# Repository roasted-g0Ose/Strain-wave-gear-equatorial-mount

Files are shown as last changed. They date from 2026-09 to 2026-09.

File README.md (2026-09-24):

# Strain Wave Gear Equatorial Mount
## What is an equatorial mount?

An **equatorial mount** is a telescope mount designed to compensate for the Earth's rotation and track celestial objects as they move across the sky. It consists of two axes known as the **right ascension (RA)** and **declination (DEC)**.

The RA axis is aligned parallel to the Earth's rotational axis, allowing the mount to rotate at the same rate as the sky appears to move. By continuously rotating around the RA axis, the mount can effectively cancel out the Earth's rotation and keep a celestial object centered in the telescope's field of view.

The DEC axis is perpendicular to the RA axis and is used to adjust the telescope's position north or south of the celestial equator. By controlling both the RA and DEC axes, the mount can slew to a specific celestial coordinate and point the telescope at a desired object in the night sky. Once positioned, the RA axis can continue tracking the object as the Earth rotates.

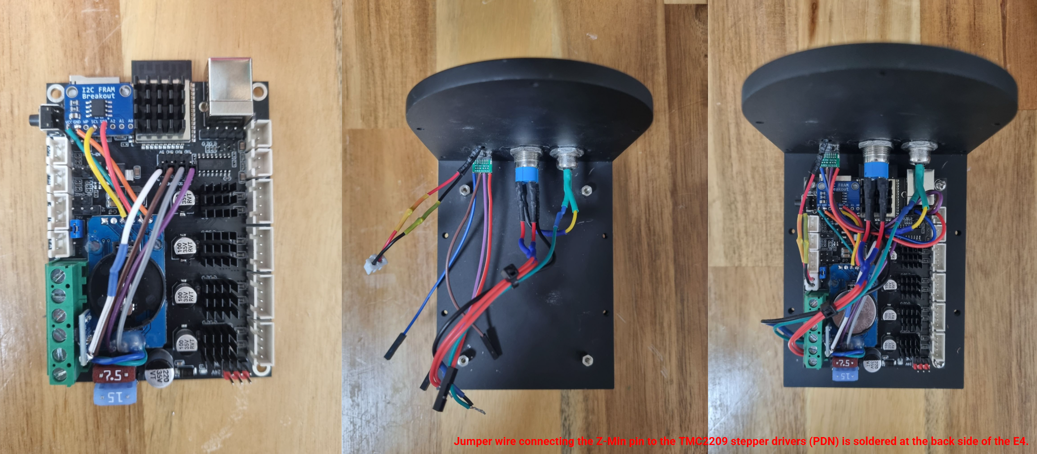
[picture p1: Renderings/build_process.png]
build_process

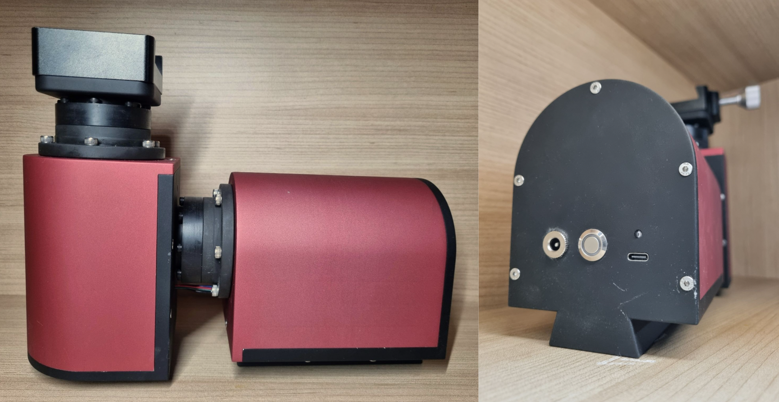
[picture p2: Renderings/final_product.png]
final_product


## Comparison of Primary Reduction Gears

When building a strain wave gear equatorial mount yourself, one of the key decisions is which primary reduction gear to use. Each type of reduction gear has its own pros and cons, summarized in the table below.

| | Planetary gear | Belt drive | Direct drive (no reduction) | Strain wave gear |
|---|---|---|---|---|
| **Backlash** | Present | None | None | None |
| **Periodic error** | Small | Almost none | None | Somewhat present |
| **Maintenance** | Barely needed | Needed (tension adjustment) | Barely needed | Barely needed |

Although the third and fourth options are attractive for their low maintenance (requiring no tension adjustment over time) and zero-backlash design, I was unaware of their existence at the time.

## Features
* FRAM module saves current position every 1000ms from start-up (home position) enabling return if there is an accidental power outage (e.g., tripping over the power cable).
* RTC module keeps track of the current time and date even when the mount is turned off.
* High reduction ratio at 2000:1 eliminates the need for electromagnetic brakes.
* Supports pulse guiding via via USB-C (USB 2.0).
* Theoretical payload of 7kg without counterweight, 12kg with counterweight.

## Bill of materials
### BOM - Electronics
| Component | Price/unit (USD)* | Quantity |
|---|---|---|
| AMS1117-3.3 3PIN | $0.34 | 1 |
| USB Type-C Female Socket | $0.37 | 1 |
| DC-099 5.5x2.1mm Female Socket | $0.47 | 1 |
| 3φ 5V LED** | $0.48 | 1 |
| 40PCS 10cm female-to-female Dupont jumper wire | $0.89 | 1 |
| 40PCS 10cm female-to-male Dupont jumper wire | $0.94 | 1 |
| 40PCS 10cm male-to-male Dupont jumper wire | $1.04 | 1 |
| MB85RC256V I2C FRAM Memory Module | $2.96 | 1 |
| DS3231 RTC Module | $2.34 | 1 |
| 12mm push button with latching reset 9-30V(12V)** | $3.15 | 1 |
| 17HS4401 NEMA17 Stepper Motor | $4.66 | 2 |
| FLE42-L2SW (20:1) | $18.46 | 2 |
| FYSETC E4 | $26.34 | 1 |
| ZXS14 (100:1, for shaft diameter of 8mm) | $85.40 | 2 |

### BOM - Mechanical
| Component | Price/unit (USD) | Quantity |
|---|---|---|
| Phillips Round Head Screw, M3 x 3 | $0.02 | 4 |
| Hex Socket Countersunk Head Screw, M3 x 12 | $0.03 | 10 |
| Hex Socket Countersunk Head Screw, M3 x 15 | $0.03 | 8 |
| PCB Standoff, M3 x 5 | $0.05 | 4 |
| Hex Socket Countersunk Head Screw, M4 x 10 | $0.05 | 8 |
| Hex Socket Head Cap Screw, M4 x 12 | $0.05 | 3 |
| Hex Socket Countersunk Head Screw, M4 x 12 | $0.05 | 4 |
| Hex Socket Head Cap Screw, M4 x 20 | $0.06 | 12 |
| Hex Socket Head Cap Screw, M6 x 10 | $0.10 | 4 |
| Hex Socket Head Cap Screw, M4 x 18 | $0.10 | 6 |
| Dovetail holder | $12.95 | 1 |
| Super Lube MULTI-PURPOSE SYNTHETIC GREASE WITH SYNCOLON (PTFE) | $18.03 | 1 |
| Loctite 638 | $18.50 | 1 |
| CNC machined parts (6 in total, tariff excluded) | $639.31 | 1 |
| Heat shrink set | $2.66 | 1 |

| | Total |
|---|---|
| **Total BOM Cost (USD)** | $951.10 |

*Calculated based on the current (Sep 7th 2026) exchange rate of 1 KRW = $0.00074.  
**Emits red light.

## Code
I made several changes to the default [OnStepX-E4](https://github.com/hjd1964/OnStepX/tree/E4) code. 

```cpp
// Extra code added under #define STATUS_LED                     ON
#define STATUS_LED_ON_STATE          HIGH
```

```cpp
// This build does not utilize weather sensors of any sort.
#define WEATHER               OFF 
```

```cpp
// Positional memory retention via Adafruit MB85RC256V FRAM breakout (I2C).

#define NV_DRIVER      NV_MB85RC256
#define MOUNT_COORDS_MEMORY      ON
```

```cpp
// Relevant steps per degree was calculated here: http://www.stellarjourney.com/assets/downloads/OnStep%20Calculations%20134.xlsx

#define AXIS1_STEPS_PER_DEGREE      35555.55556
#define AXIS2_STEPS_PER_DEGREE      35555.55556
```

```cpp
// These options can be toggled ON and OFF for reversal of direction of rotation. 
// As you can see, my RA axis was somewhat rotating in the wrong direction.

#define AXIS1_REVERSE      ON
#define AXIS2_REVERSE      OFF
```

```cpp
// DS3231 settings were left at default. 
#define TIME_LOCATION_SOURCE       DS3231
```

```cpp
// Not a worm gear mount, fast guiding compensates for PE (Periodic Error)
#define PEC_STEPS_PER_WORM_ROTATION        0
```
```cpp
#define TRACK_AUTOSTART      ON
```

```cpp
// Although adjustable at run-time from 1/2 to 2x this rate, it is not recommended to go over 1.0 deg/sec as it may cause step-out.
#define SLEW_RATE_BASE_DESIRED        1.0

```

For uploading instructions, please refer to [OnStep Wiki](https://onstep.groups.io/g/main/wiki/32794). Although the wiki does not mention it explicitly, you will need to install the latest Adafruit BusIO library since this is a dependency for the Adafruit BME280 library (I have included ZIP files of [required libraries](./SW/Libraries/) inside the repository).

## Troubleshooting
### No response to serial commands (`:GVP#` returns nothing)
**Cause:** `NV_DRIVER` was set to `NV_MB85RC256` (external I2C FRAM) before the FRAM module was wired up. OnStepX hung indefinitely trying to write defaults to a non-existent NV device, so it never reached the point of starting the command channel.

**Fix:** Wire the FRAM to I2C before power-on, or temporarily switch `NV_DRIVER` to `NV_DEFAULT` (internal flash) if testing without it. After connecting/switching NV devices, run one `NV_WIPE ON` → upload → power cycle → wait ~1 min → `NV_WIPE OFF` → upload cycle to initialize the device's defaults.

### Status LED never lights
**Cause:** `STATUS_LED_PIN` on the E4 is routed through a MOSFET-switched fan header (V-Fan), which is active-HIGH. OnStepX's default LED logic assumes a raw cathode-sink pin (active-LOW), so it was driving the pin the opposite way needed to turn the LED on.

**Fix:** Add `#define STATUS_LED_ON_STATE HIGH` below `STATUS_LED ON` in Config.h.

### NINA shows ASCOM checksum / invalid drive rate errors
**Cause:** `DEBUG` was left set to `VERBOSE` in Extended_config.h. Since `SERIAL_DEBUG` shares the same physical port as the command channel (`SERIAL_A`), debug text was interleaved with LX200 protocol replies, corrupting what NINA received.

**Fix:** Set `DEBUG OFF` for normal operation; only enable `VERBOSE` for boot-log diagnostics with NINA disconnected.

### Status LED (and mount state) resets when opening the NINA OnStep Telescope Setup tab
**Cause:** ESP32 dev boards including the E4 have a built-in auto-reset circuit. The DTR and RTS lines from the USB-serial chip are wired through transistors to the ESP32's EN (reset) pin. This was originally intended to let the Arduino IDE reset the board automatically during firmware uploads. However, any application that opens the COM port, including NINA and ASCOM, can inadvertently trigger a reset. If RTS is held low while the port remains open, it can even keep the board in a reset state for the entire time the tab is open.

The behavior was inconsistent. Sometimes the LED would come back on after a full reboot cycle, but often it would never come back at all. This is likely caused by repeated connection retries reasserting DTR during the reboot process before the board has a chance to finish booting.

**Fix (soft and hard fixes):**
* In the ASCOM OnStep driver's Setup dialog, set the Serial Interface baud dropdown to the **"no DTR control"** variant. This does not prevent Status LED reset upon opening the NINA OnStep Telescope Setup tab, but makes sure the LED comes back on after a full reboot cycle.
* In Windows Device Manager → Ports → [COM port] → Properties → Port Settings → Advanced, enable **"Disable Modem Ctrl Handshaking."** This completely prevents Status LED reset.

### NINA's home position function does not work and GOTO function immediately settles
**Cause:** FRAM module is corrupt.

**Fix:** Replace FRAM.

### Mount behaves normally when the housing is not mounted, while it behaves abnormally when the housing is mounted
**Cause:** The reset switch on the board is physically pressed against the mount housing.

**Fix:** Trim off the end of the reset switch.

## Room for further improvement
* 3D print a non-metallic panel to provide easier access to the mount's power and control interfaces.

* Use a strain wave gear as the primary reducer instead of planetary gear to eliminate backlash while maintaining a high reduction ratio.

* Add a buzzer to provide audible feedback on the mount's status, making it possible to monitor its state without having to look at the mount.

* Add another opening for the onboard USB-B connector. It is structurally more rigid and can serve as a backup interface in the field if the USB-C port fails.

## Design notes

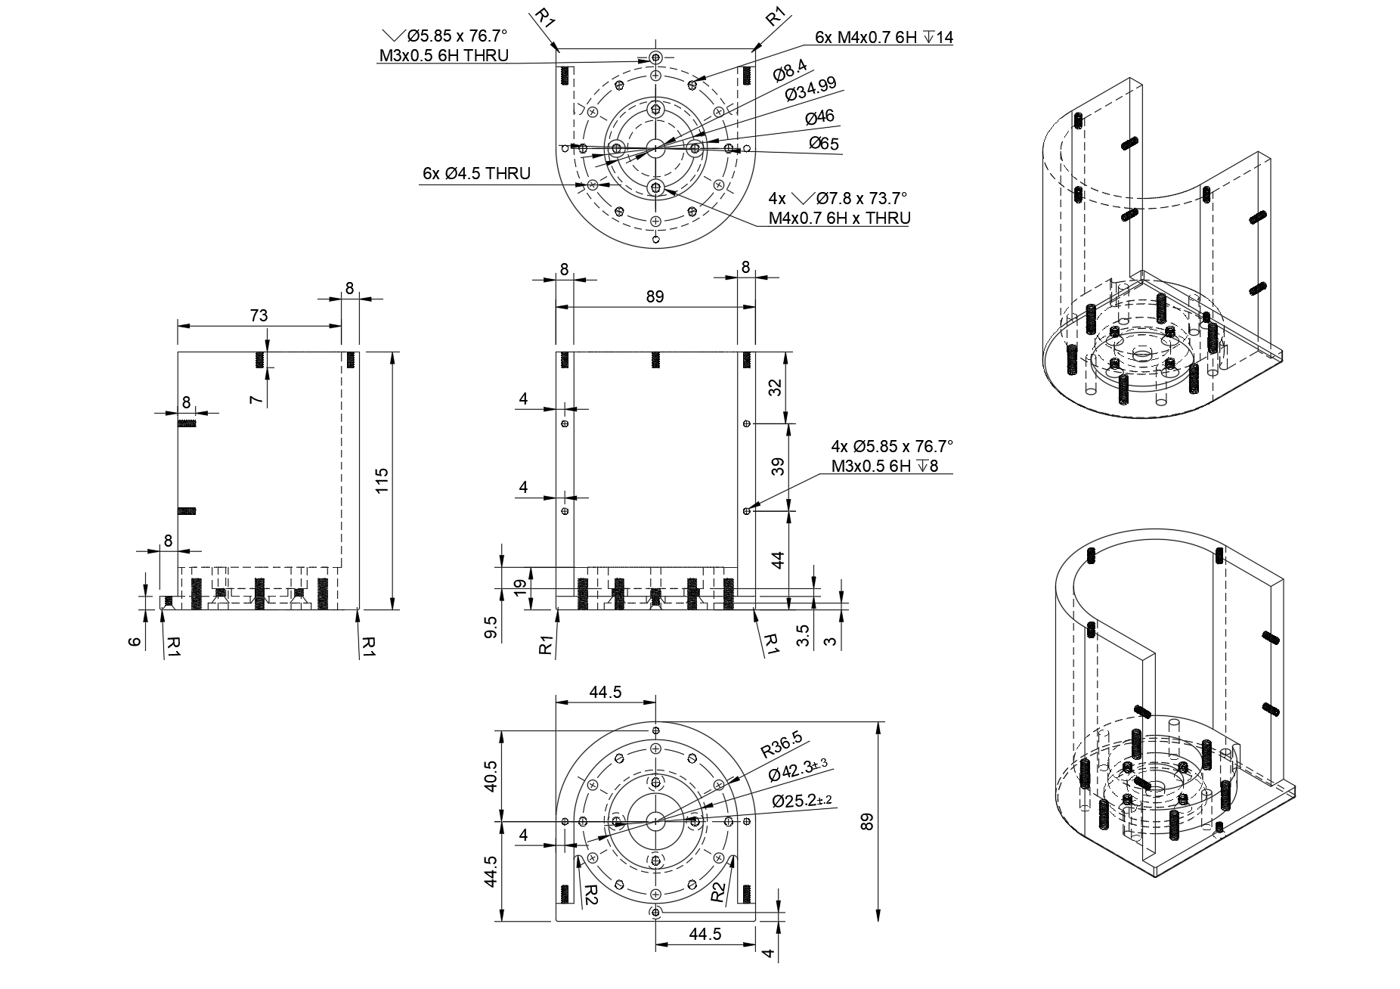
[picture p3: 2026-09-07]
2D Drawings/Declination/DEC1 Drawing.png

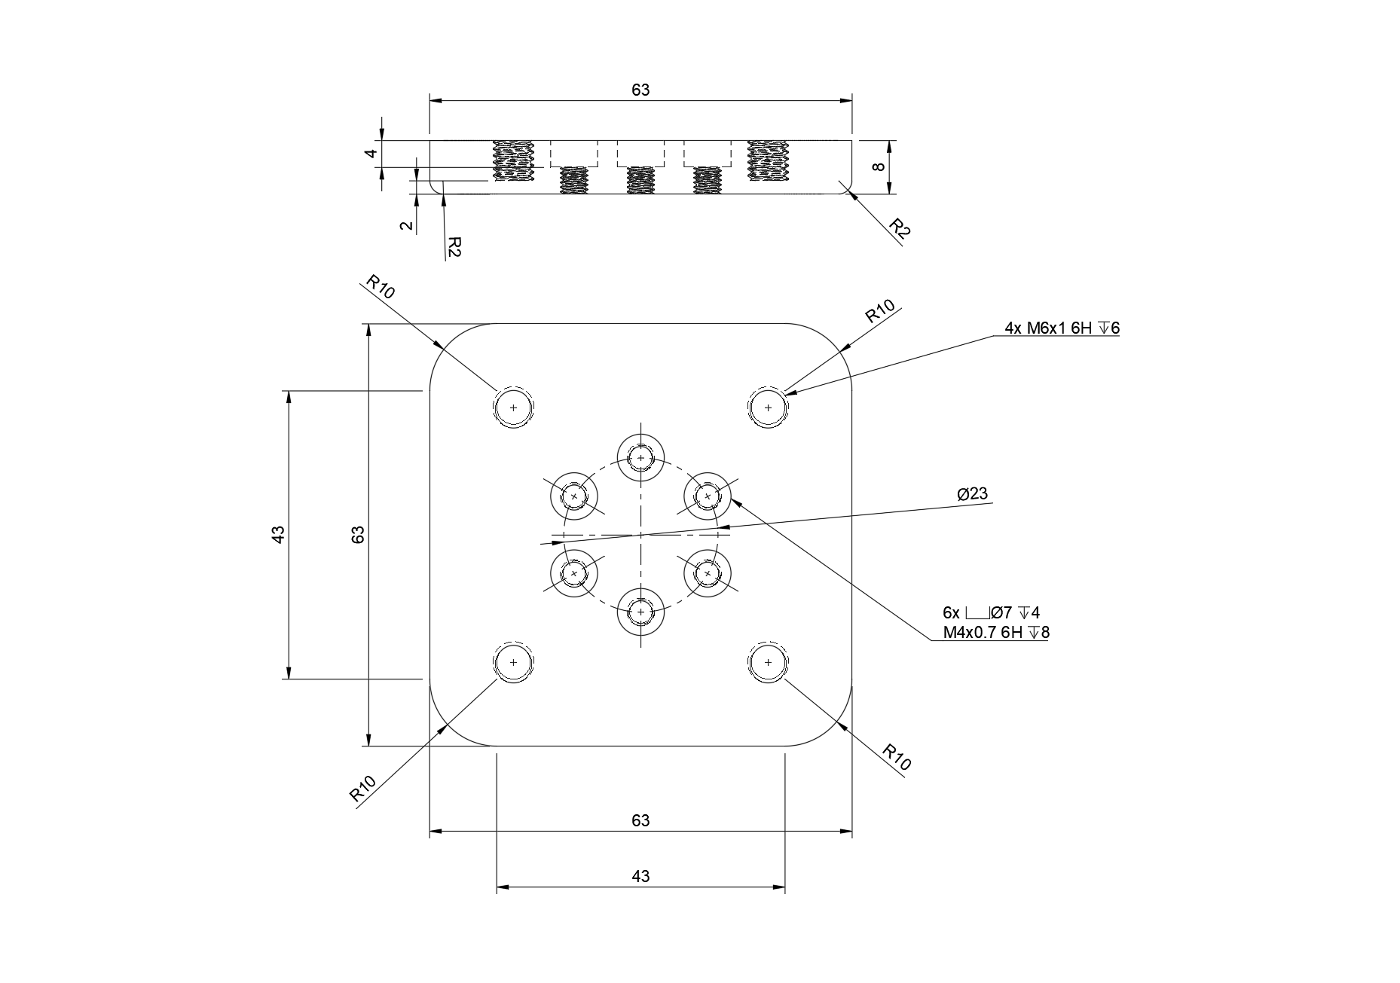
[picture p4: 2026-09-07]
2D Drawings/Declination/Clamp-harmonic Adapter Drawing.png

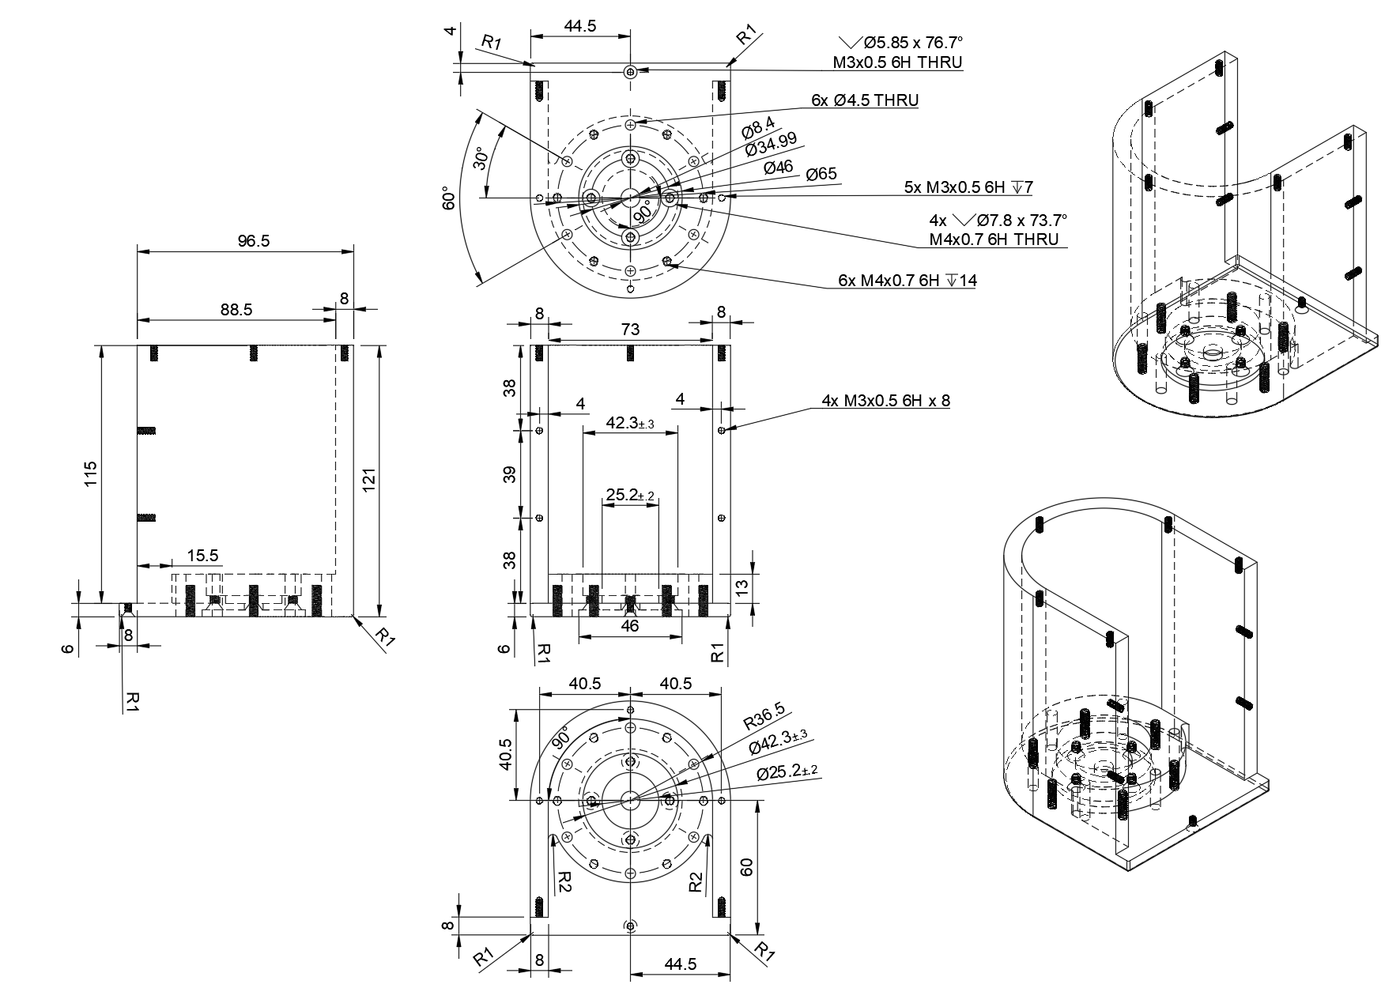
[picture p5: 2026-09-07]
2D Drawings/Right Ascension/RA1 Drawing.png

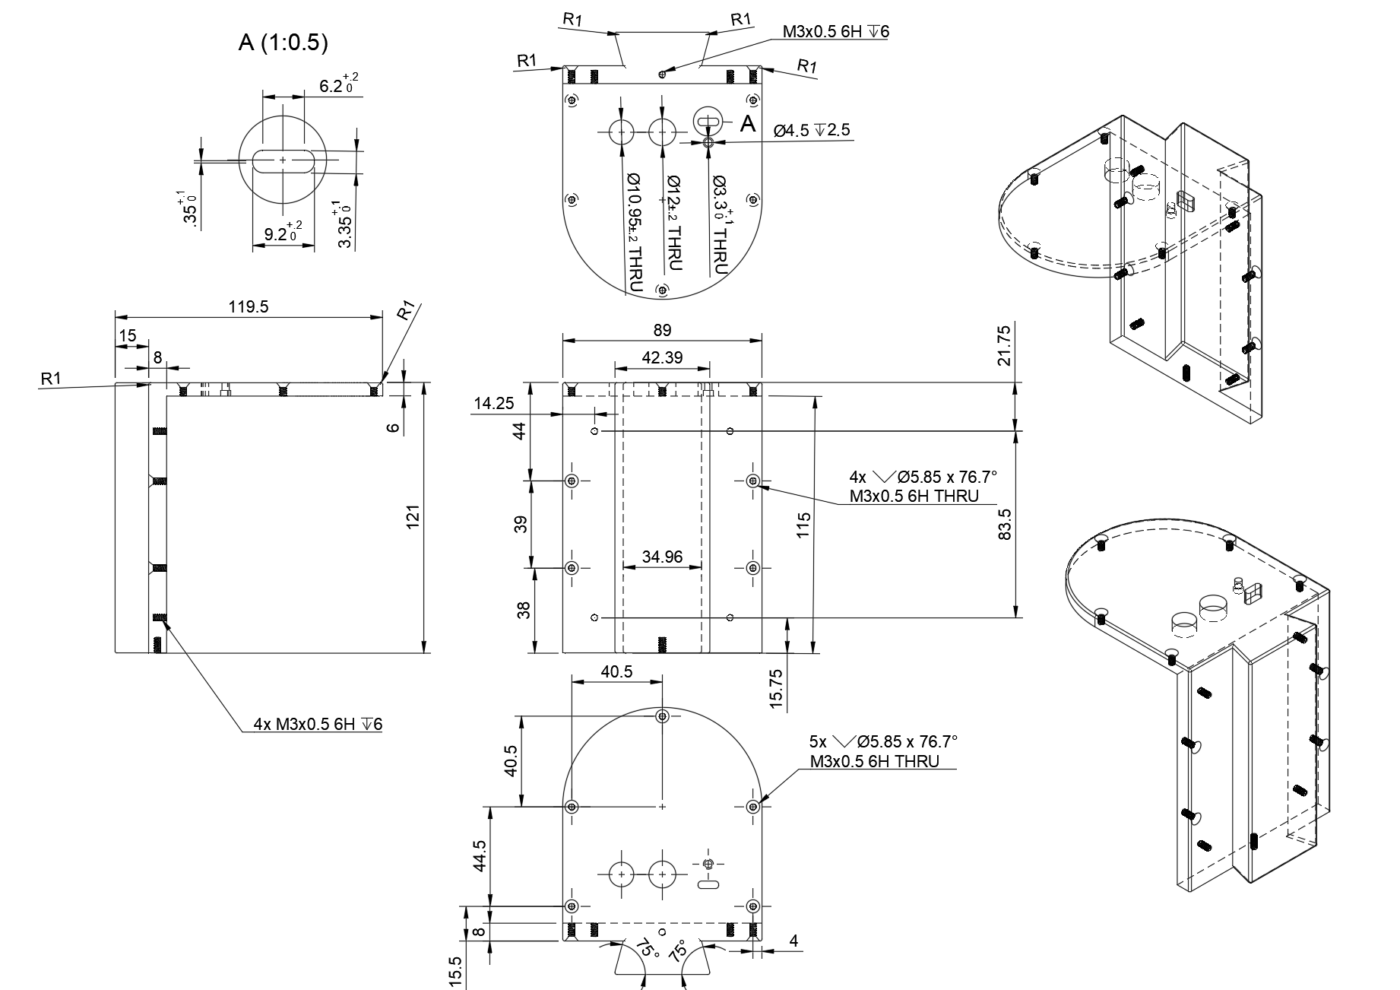
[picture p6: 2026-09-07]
2D Drawings/Right Ascension/RA2 Drawing.png

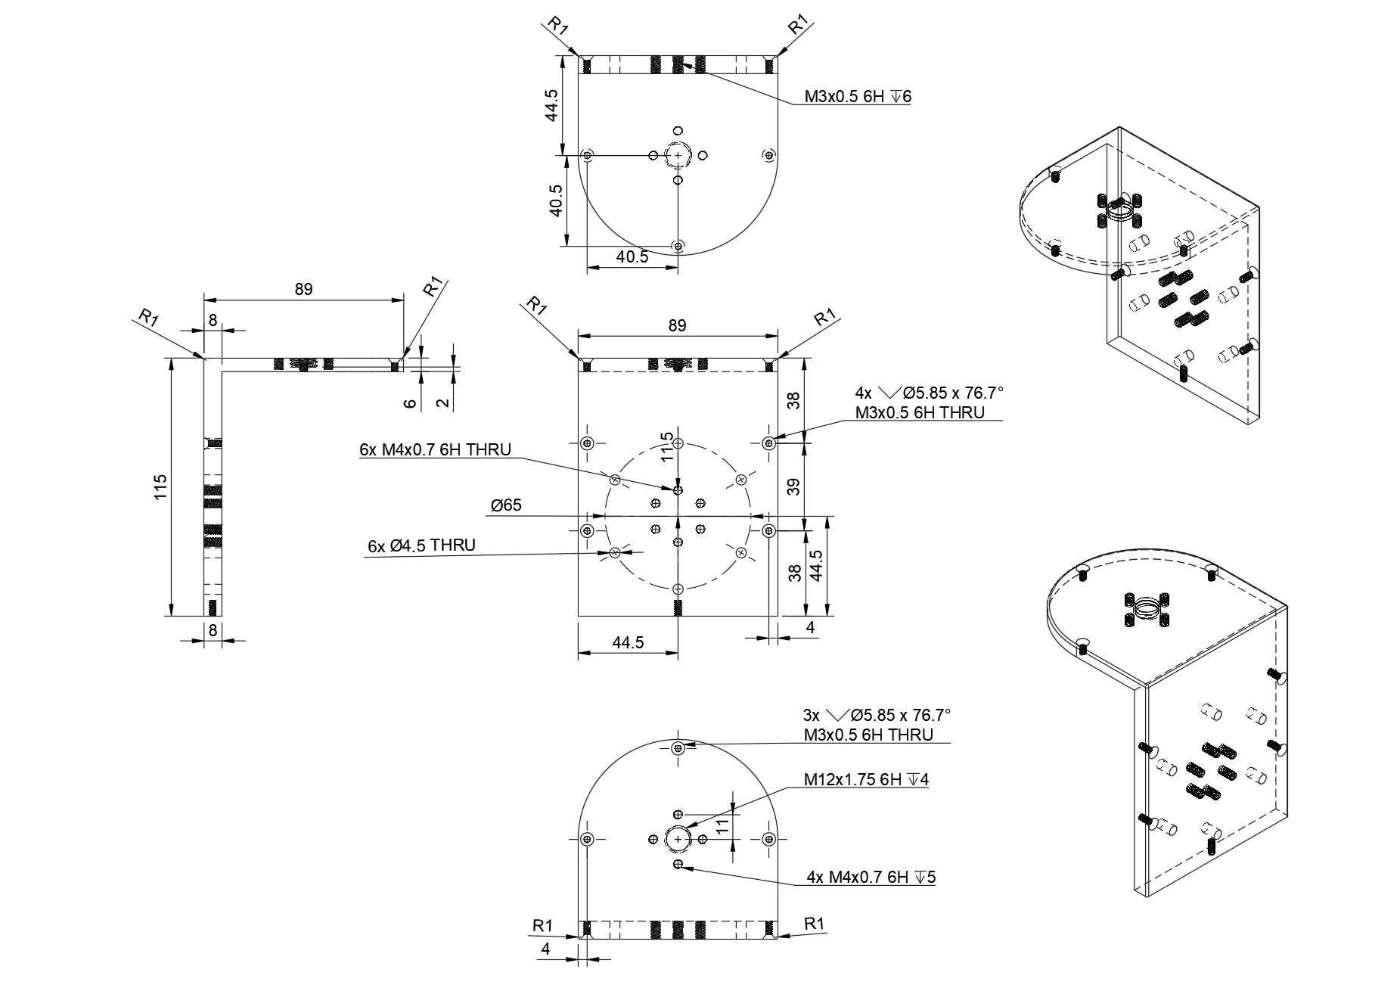
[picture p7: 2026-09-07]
2D Drawings/Declination/DEC2 Drawing.png

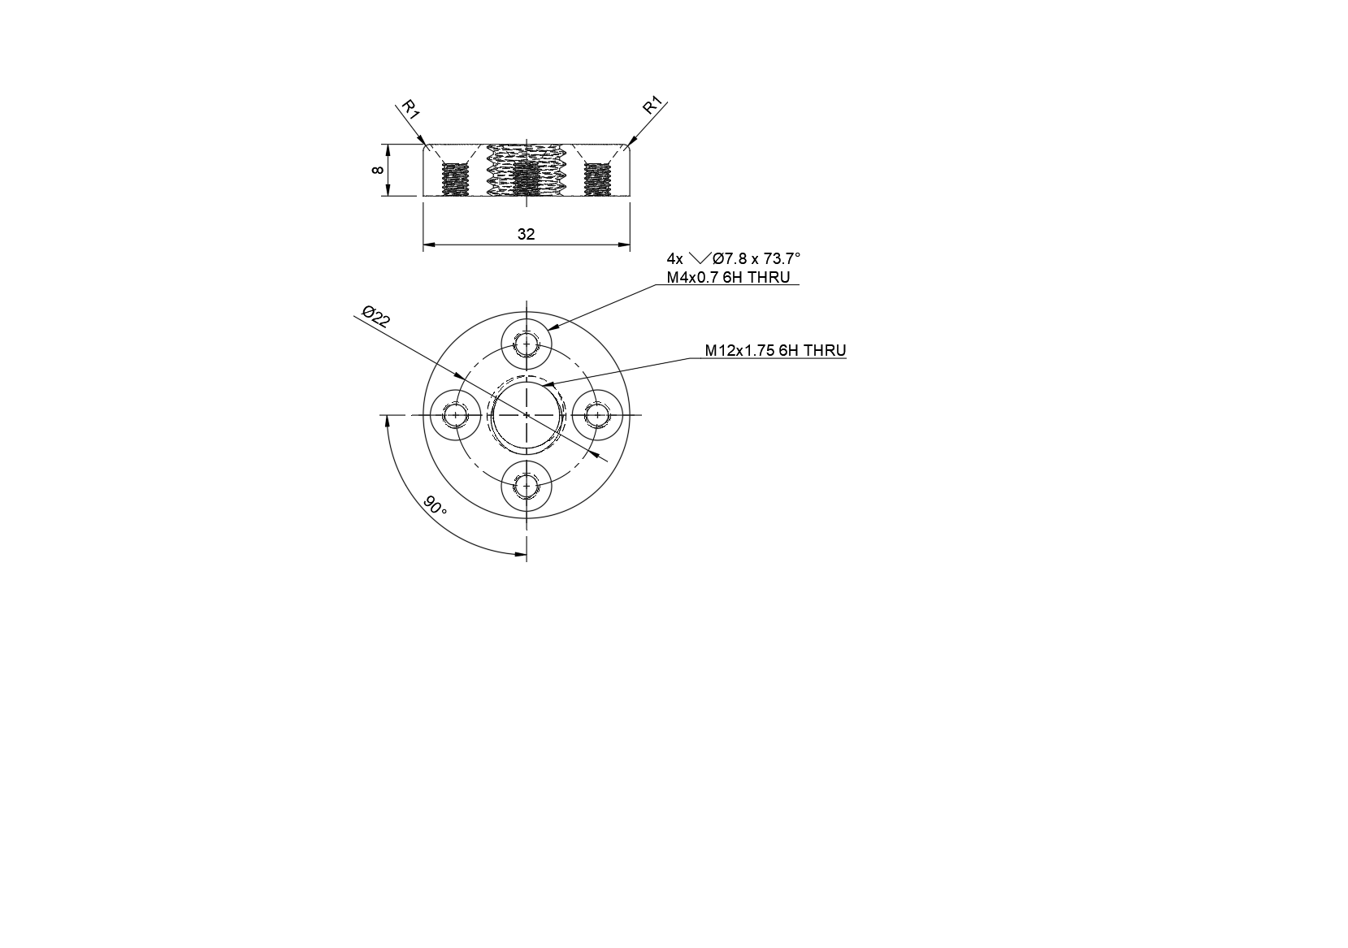
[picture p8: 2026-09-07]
2D Drawings/Declination/Counterweight Shaft Holder Drawing.png

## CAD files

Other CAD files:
3D Models/Assembly.step
3D Models/Declination/DEC1.step
3D Models/Right Ascension/RA1.step
3D Models/Declination/Clamp-harmonic Adapter.step
3D Models/Right Ascension/RA2.step
3D Models/Declination/Counterweight Shaft Holder.step
3D Models/Declination/DEC2.step

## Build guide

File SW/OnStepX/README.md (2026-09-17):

OnStepX Telescope Controller
===========================
# What is OnStepX?
OnStepX is the advanced version of the OnStep computerized telescope controller with support for interfacing with/controlling a variety of motor drivers (and so motors) including Step/Dir, ODrive, and Servo (a combination of encoder and DC motor or Stepper motor) types.

It supports:
* Telescope Mount control (Alt/Azm and Equatorial GEM/Fork.)  Optional support for Eq mounts with Tangent Arm Declination.  Usually the Goto capability is enabled, but that's optional as well for those who just want basic mount control.
* Telescope Rotator control (including Alt/Azm de-rotation.)
* Telescope Focuser control (up to 6 focusers so it can handle collimation as well as focusing.)
* Telescope Accessory control (combination of up to 8 dew-heaters, switches, analog PWM.)

# Features
OnStepX supports a wide variety of connection options.  Several serial
"command channels" can be utilized. One of the these is normally devoted to a USB
connection and for the other(s) choose from the following:

* Bluetooth
* ESP8266 WiFi
* Arduino M0/Ethernet Shield
* Even another USB port or RS232 serial isn't very difficult to add.

In the case of running OnStepX on an ESP32 it can provide its own Bluetooth or WiFi IP command channels without additional hardware by simply activating the feature in OnStepX.

Other software in the OnStep ecosystem include:

* an [ASCOM](http://ascom-standards.org/) driver (with IP and Serial support),
* an Android App useable over WiFi or Bluetooth equipped Phones/Tablets,
* a "built-in" website (on the Ethernet and/or WiFi device),
* a full planetarium program that controls all features ([Sky Planetarium](http://stellarjourney.com/index.php?r=site/software_sky)).

OnStep is compatible with the LX200 protocol. This means it can be controlled
from other planetarium software, like: Sky Safari, CdC (even without ASCOM),
Stellarium, etc.

There are also [INDI](http://www.indilib.org/about.html) drivers so it can be used from Linux, with CdC or KStars.

# Documentation
Detailed documentation, including the full set of features, detailed designs for
PCBs, instructions on how to build a controller, how to configure the firmware
for your particular mount, can all be found the [OnStep Group Wiki](https://groups.io/g/onstep/wiki/home).

# Change Log
All the changes are tracking in git, and a detailed list can be accessed using the
following git command:
 
git log --date=short --pretty=format:"%h %ad %<(20)%an %<(150,trunc)%s"

# Support
Questions and discussion should be on the mailing list (also accessible via the
web) at the [OnStep Group](https://groups.io/g/onstep/).

# License
OnStep is open source free software, licensed under the GPL.

See [LICENSE.txt](./LICENSE.txt) file.

# Author
[Howard Dutton](http://www.stellarjourney.com)

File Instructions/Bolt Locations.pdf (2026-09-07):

Hex Socket Head Cap Screw, M4 x 20 (Qty: 6)

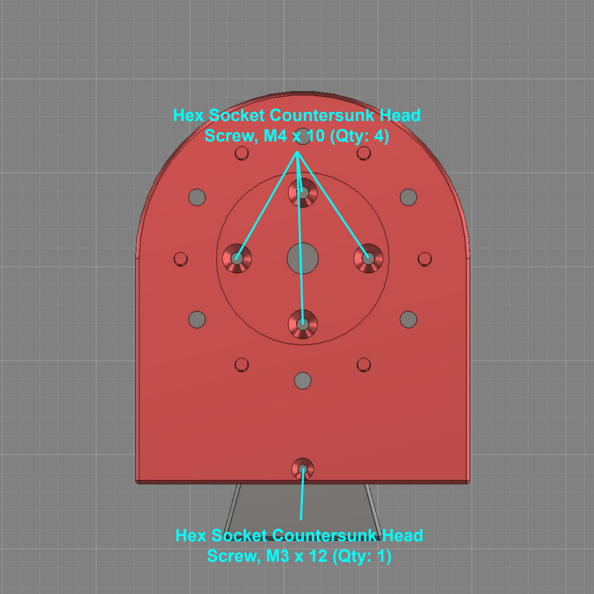
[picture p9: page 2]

Hex Socket Countersunk Head Screw, M4 x 10 (Qty: 4)

Hex Socket Countersunk Head Screw, M3 x 12 (Qty: 1)

Hex Socket Countersunk Head Screw, M3 x 15 (Qty: 4)

Hex Socket Countersunk Head Screw, M3 x 12 (Qty: 4)

PCB Standoff, M3 x 5 (Qty: 4) + Phillips Round Head Screw, M3 x 3 (Qty: 4)

Hex Socket Head Cap Screw, M4 x 12 (Qty: 3)

Hex Socket Head Cap Screw, M6 x 10 (Qty: 4)

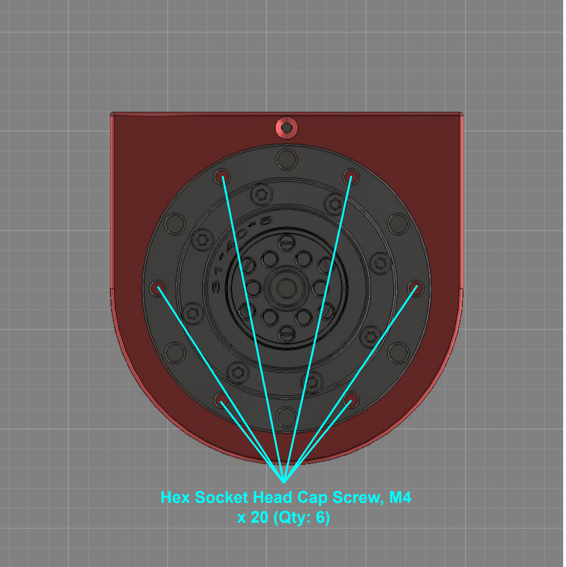
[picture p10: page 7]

Hex Socket Head Cap Screw, M4 x 20 (Qty: 6)

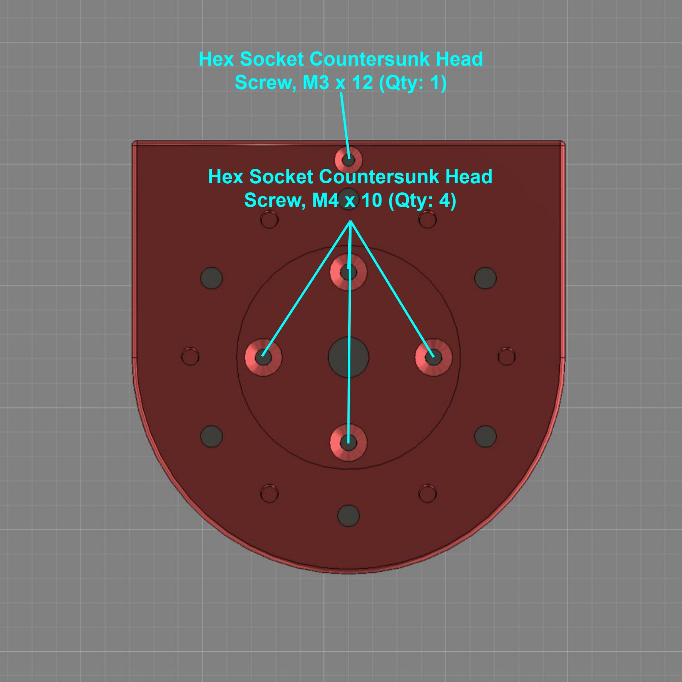
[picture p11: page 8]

Hex Socket Countersunk Head Screw, M4 x 10 (Qty: 4)

Hex Socket Countersunk Head Screw, M3 x 12 (Qty: 1)

Hex Socket Countersunk Head Screw, M4 x 12 (Qty: 4)

Hex Socket Countersunk Head Screw, M3 x 12 (Qty: 4)

Hex Socket Countersunk Head Screw, M3 x 15 (Qty: 4)

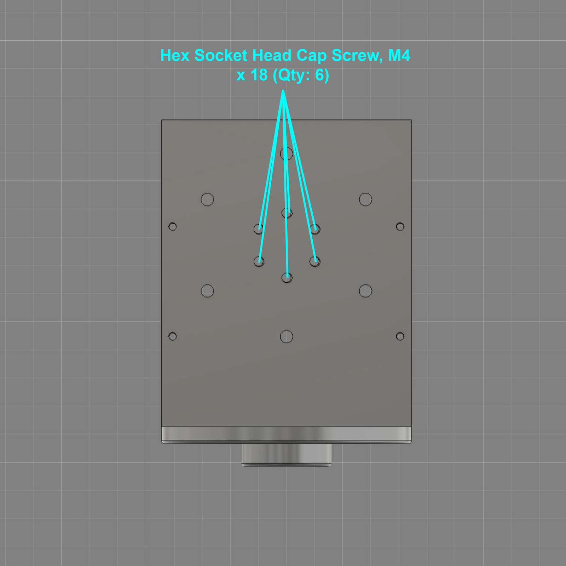
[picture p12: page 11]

Hex Socket Head Cap Screw, M4 x 18 (Qty: 6)

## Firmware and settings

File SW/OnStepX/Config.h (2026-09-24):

/* ---------------------------------------------------------------------------------------------------------------------------------
 * Configuration for OnStepX
 *
 *          For more information on setting OnStep up see http://www.stellarjourney.com/index.php?r=site/equipment_onstep 
 *                      and join the OnStep Groups.io at https://groups.io/g/onstep
 * 
 *           *** Read the compiler warnings and errors, they are there to help guard against invalid configurations ***
 *
 * ---------------------------------------------------------------------------------------------------------------------------------
 * ADJUST THE FOLLOWING TO CONFIGURE YOUR CONTROLLER FEATURES ----------------------------------------------------------------------
 * <-Req'd = always must set, <-Often = usually must set, Option = optional, Adjust = adjust as req'd, Infreq = infrequently changed
*/
//      Parameter Name              Value   Default  Notes                                                                      Hint

// =================================================================================================================================
// CONTROLLER ======================================================================================================================

#define THERMISTOR1_TNOM               25 //         Nominal temperature (Celsius)
#define THERMISTOR1_RNOM            10000 //         Nominal resistance (Ohms) at nominal temperature
#define THERMISTOR1_BETA             3950 //         Beta coefficient
#define THERMISTOR1_RSERIES          4700 //         Series resistor value (Ohms)
//#define THERMISTOR_RPARALLEL      10000 //         Parallel resistor value (Ohms, requires adding the 10k resistors to TB/TE!)
                                          //         Option to extend the temperature measurement range down to -20C or so

#define LIMIT_SENSE_PIN                34 //         Override default and move limit sense to the FYSETC E4's X-MIN connector
#define SERIAL_TMC_RX                  35 //         Override default TMC2209 RX pin move to Y-MIN (enable _DRIVER_STATUS to use)

#define DISPLAY_WEATHER                ON //         Website, display weather
#define DISPLAY_INTERNAL_TEMPERATURE   ON //         Website, display internal MCU temperature

// PINMAP ------------------------------------------------- see https://onstep.groups.io/g/main/wiki/Configuration_Controller#PINMAP
#define PINMAP                  FYSETC_E4 //    OFF, Choose from: MiniPCB, MiniPCB2, MaxPCB2, MaxESP3, CNC3, STM32Blue,      <-Req'd
                                          //         MaxSTM3, FYSETC_S6_2, etc.  Other boards and more info. in ~/src/Constants.h

// SERIAL PORT COMMAND CHANNELS --------------------- see https://onstep.groups.io/g/main/wiki/Configuration_Controller#SERIAL_PORTS
#define SERIAL_A_BAUD_DEFAULT        9600 //   9600, n. Where n=9600,19200,57600,115200,230400,460800 (common baud rates.)    Infreq
#define SERIAL_B_BAUD_DEFAULT         OFF //   9600, n. Baud rate as above. See (src/pinmaps/) for Serial port assignments.   Infreq
#define SERIAL_B_ESP_FLASHING         OFF //    OFF, ON Upload ESP8266 WiFi firmware through SERIAL_B with :ESPFLASH# cmd.    Option
#define SERIAL_C_BAUD_DEFAULT         OFF //    OFF, n. Baud rate as above. See (src/pinmaps/) for Serial port assignments.   Infreq
#define SERIAL_D_BAUD_DEFAULT         OFF //    OFF, n. Baud rate as above. See (src/pinmaps/) for Serial port assignments.   Infreq
#define SERIAL_E_BAUD_DEFAULT         OFF //    OFF, n. Baud rate as above. See (src/pinmaps/) for Serial port assignments.   Infreq
#define SERIAL_RADIO    WIFI_ACCESS_POINT //    OFF, Use BLUETOOTH or WIFI_ACCESS_POINT or WIFI_STATION (ESP32 only.)         Option

// STATUS --------------------------------------------- see https://onstep.groups.io/g/main/wiki/Configuration_Controller#STATUS_LED
#define STATUS_LED                     ON //    OFF, Steady illumination if no error, blinks w/error code otherwise.          Option
#define STATUS_LED_ON_STATE          HIGH

// RETICLE CONTROL ------------------------------- see https://onstep.groups.io/g/main/wiki/Configuration_Controller#RETICLE_CONTROL
#define RETICLE_LED_DEFAULT           OFF //    OFF, n. Where n=0..255 (0..100%) activates feature sets default brightness.   Option
#define RETICLE_LED_MEMORY            OFF //    OFF, ON Remember reticle brightness across power cycles.                      Option
#define RETICLE_LED_INVERT            OFF //    OFF, ON Inverts control for cases where 0V is max brightness.                 Option
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

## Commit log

2026-09-07 Add initial files
    [Assembly.step, Clamp-harmonic Adapter.step, Counterweight Shaft Holder.step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]
2026-09-23 Update README with USB-B connector details
